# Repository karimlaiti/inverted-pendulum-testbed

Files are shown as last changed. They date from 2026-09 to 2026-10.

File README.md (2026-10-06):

# Inverted Pendulum Mechatronic Testbed (Linear Rail MGN12)




[]()

Physical mechatronic testbed and control architecture for experimental research and validation of **nonlinear control (Åström-Furuta Lyapunov Energy Swing-Up)**, **asymptotic optimal control (5-State CARE LQR with anti-drift integral action)**, and **nonlinear state estimation (3-State EKF at 200 Hz)** on a motorized MGN12 linear rail.

---

## System Identification & Physical Constants

| Parameter | Symbol | Identified Value | Units | Description |
| :--- | :---: | :---: | :---: | :--- |
| **Cart Mass** | $M$ | $0.380$ | $\text{kg}$ | Carriage platform + MGN12H block + encoder mount |
| **Pendulum Mass** | $m$ | $0.020$ | $\text{kg}$ | Carbon fiber tube ($7\text{g}$) + tip mass ($10\text{g}$) + hub ($3\text{g}$) |
| **Total Rod Length** | $L$ | $0.200$ | $\text{m}$ | $200\text{ mm}$ pultruded carbon fiber tube |
| **Center of Mass (COM)** | $l$ | $0.135$ | $\text{m}$ | $l = \frac{m_r (L/2) + m_{\text{tip}} L}{m} = 0.135\text{ m}$ |
| **Moment of Inertia (Pivot)** | $J$ | $4.933 \times 10^{-4}$ | $\text{kg}\cdot\text{m}^2$ | $J = \frac{1}{3} m_r L^2 + m_{\text{tip}} L^2$ |
| **Natural Frequency** | $\omega_0$ | $7.328$ | $\text{rad/s}$ | $\omega_0 = \sqrt{\frac{m g l}{J}} \implies T_0 \approx 0.857\text{ s}$ |
| **Input Coupling** | $\alpha$ | $5.473$ | $\text{rad}/(\text{m}\cdot\text{s}^2)$ | Acceleration coupling: $\alpha = \frac{m l}{J}$ |
| **Target Swing-Up Energy** | $E_0$ | $0.0530$ | $\text{J}$ | $E_0 = 2 m g l$ |
| **Actuator & Driver** | -- | NEMA 17 + TMC2209 | -- | $24\text{V DC}$ Mean Well, $1/16$ microstepping, $430\text{ RPM}$ |
| **Rotary Optical Encoder** | -- | OMCH E6B2-CWZ6C | -- | $1200\text{ P/R}$ ($4800\text{ counts/rev}$ in $4\times$ quadrature, $0.075^\circ$) |

---

## Control Architecture

The system operates as a hybrid finite-state machine (FSM) transitioning between nonlinear energy pumping and asymptotic linear balancing:

- **State Estimation ($200\text{ Hz}$)**: 3-state Extended Kalman Filter (EKF) estimating pendulum angle $\theta$, angular velocity $\omega$, and sensor bias.
- **Energy Swing-Up ($|\theta| > 22^\circ$)**: Åström-Furuta Lyapunov energy shaping with deficit-modulated cart acceleration and soft-limit boundary centering.
- **LQR Balance ($|\theta| \le 22^\circ$)**: 5-state continuous CARE LQR with cart position integral action ($x_I$) for zero steady-state tracking error and full left-half-plane pole placement.
- **Actuation ($50\text{ kHz}$)**: Hardware Timer1 interrupt step engine generating direct STEP/DIR pulses for the TMC2209 driver at $24\text{V}$.

### 1. 5-State LQR Balance Synthesis
To prevent limit-cycle oscillations caused by non-minimum phase zero dynamics, the system is modeled with extended cart integral action:
$$z = \begin{bmatrix} x_I & x & v & \theta & \omega \end{bmatrix}^T$$

$$a_{\text{cmd}} = (K_\theta \theta + K_\omega \omega) + (K_x x + K_v v + K_{xi} x_I)$$

Tuned feedback gains:
$$K = \begin{bmatrix} 1.80 & 12.50 & 12.20 & 62.43 & 9.50 \end{bmatrix}$$

**Closed-Loop Eigenvalues**:
$$\lambda(A_{\text{cl}}) = \{-34.53, -3.01, -0.17, -1.85 \pm 1.42j\}$$
*All 5 poles reside strictly in the Left Half Plane ($\operatorname{Re}(\lambda) < 0$), proving asymptotic stability.*

### 2. Nonlinear Dynamics Benchmark

<picture>
  <source media="(prefers-color-scheme: dark)" srcset="simulation/benchmark_dynamics_dark.png">
  <source media="(prefers-color-scheme: light)" srcset="simulation/benchmark_dynamics.png">
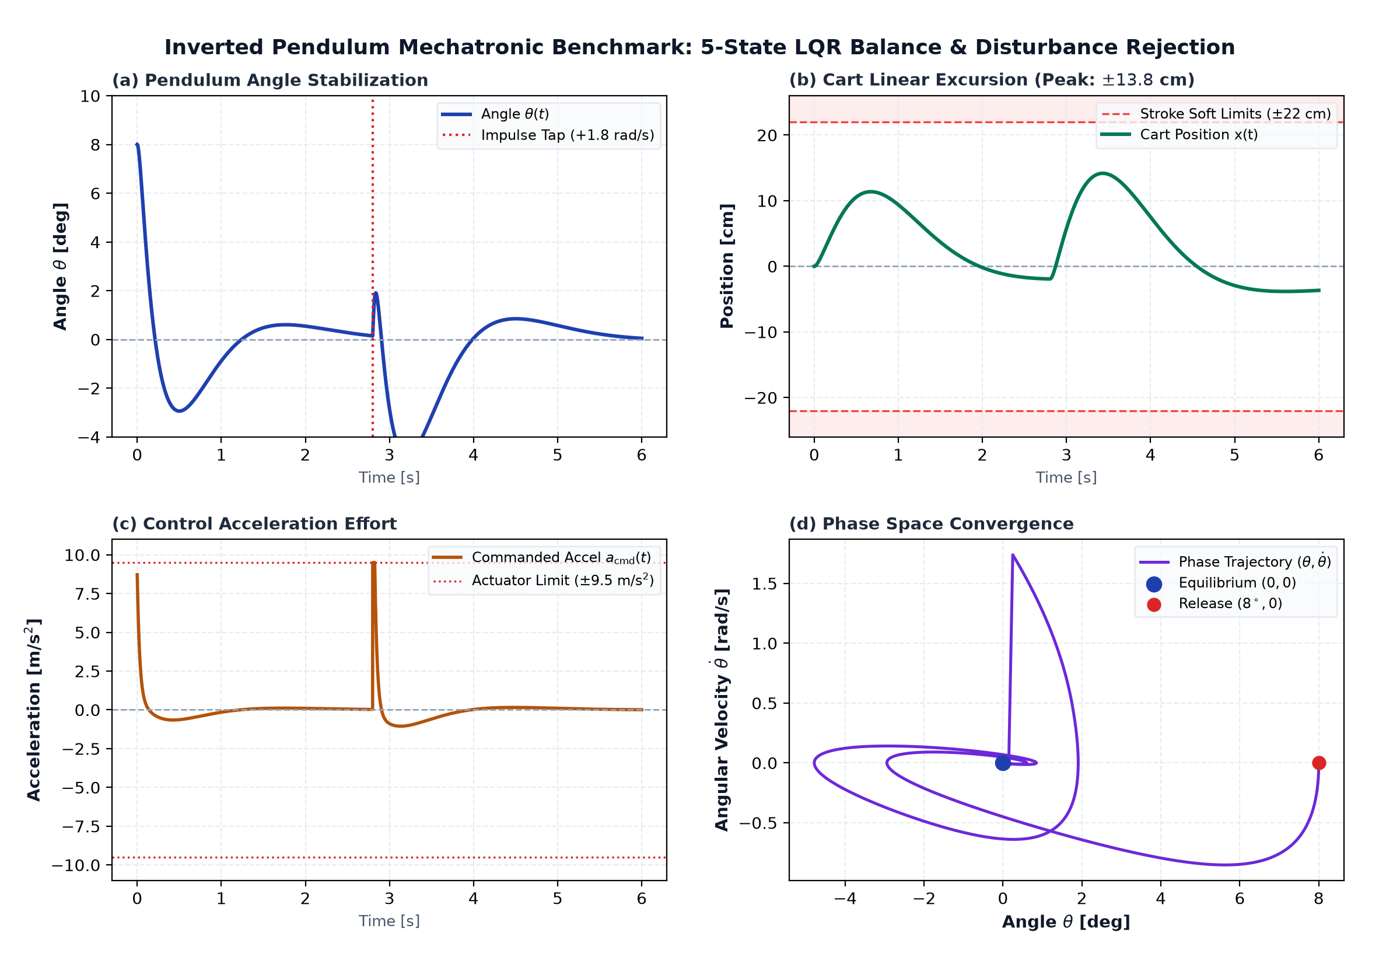
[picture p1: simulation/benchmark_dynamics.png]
Inverted Pendulum Dynamics Benchmark
  
</picture>

---

## Repository Structure

```
inverted-pendulum-testbed/
├── config/
│   └── system_params.yaml         # Physical constants, LQR weights, and calibrated gains
├── docs/
│   └── theory_and_firmware_guide.md # Comprehensive Lagrangian derivations and EKF proofs
├── firmware/                      # Production embedded C++ firmware (PlatformIO)
│   ├── platformio.ini             # ESP8266 build configuration (80 MHz, 460800 baud flash)
│   ├── include/                   # Modular C++ control & estimation headers
│   │   ├── config.h               # Hardware pinout, system ID constants, and gain parameters
│   │   ├── controllers.h          # Hybrid FSM supervisor, 5-state LQR & Lyapunov swing-up
│   │   ├── ekf_estimator.h        # 3-state EKF observer with phase unwrap
│   │   ├── encoder.h              # OMCH optical encoder 4-bit quadrature decoder ISR
│   │   ├── serial_cli.h           # 10 Hz telemetry streaming & runtime CLI
│   │   └── stepper_timer.h        # 50 kHz Timer1 hardware step generator
│   └── src/
│       └── main.cpp               # Main setup and 200 Hz real-time control loop
├── simulation/                    # RK4 simulation, interactive GUI & serial telemetry
│   ├── simulate_pendulum.py       # YAML-driven simulation with disturbance injection
│   ├── interactive_gui.py         # Hardware-accelerated PySide6 2D simulator with live oscilloscope
│   ├── live_telemetry.py          # Real-time serial telemetry dashboard from hardware
│   ├── render_swiss_industrial_simulation.py # Swiss/IEEE academic video render generator
│   ├── render_complete_swingup_video.py      # 60fps swing-up & LQR balance video renderer
│   ├── benchmark_dynamics.png     # Disturbance response plots (IEEE Light)
│   ├── benchmark_dynamics_dark.png # Disturbance response plots (Swiss Dark HUD)
│   └── web_simulator/
│       └── index.html             # Standalone zero-dependency HTML5/Canvas interactive simulator
├── cad/                           # 3D mechanical models and CAD assembly
│   └── README.md
├── requirements.txt
└── README.md
```

---

## Quickstart

### 1. Interactive Desktop Simulation (Python + PySide6)
Starts at rest from the bottom ($\theta = 180^\circ$), performs resonant energy swing-up, and catches into 5-state LQR balancing:
```bash
# Install dependencies
pip install -r requirements.txt

# Launch PySide6 interactive simulator
python simulation/interactive_gui.py
```
*Interactive controls: Mouse drag on cart or pendulum tip to inject arbitrary perturbations in real time, buttons for impulse disturbance ($\pm 3\,\text{N}$), target cart setpoint slider, and live oscilloscope for angle $\theta(t)$ and position $x(t)$.*

### 2. Zero-Dependency Web Simulator (HTML5 / Canvas)
Open `simulation/web_simulator/index.html` directly in any modern browser (Chrome, Firefox, Safari) with zero installation required:
```bash
# Launch via browser directly
xdg-open simulation/web_simulator/index.html
```

### 3. Numerical Benchmark & Disturbance Rejection
```bash
python simulation/simulate_pendulum.py
```

### 4. Live Hardware Telemetry Dashboard
```bash
python simulation/live_telemetry.py /dev/ttyUSB0
```

### 4. Build & Flash Embedded Firmware (PlatformIO)
```bash
cd firmware
pio run -t upload
pio device monitor -b 115200
```

---

## Author
**Karim Laiti**  
*M.Sc. Control Engineering & Robotics — Sapienza University of Rome*  
*B.Sc. Automation Engineering — University of Bologna*  
Portfolio: [karimlaiti.github.io](https://karimlaiti.github.io)

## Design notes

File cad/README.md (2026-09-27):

# CAD & 3D Mechanical Assembly

This directory is reserved for custom-designed mechanical CAD models and manufacturing files:
* Pultruded carbon-fiber shaft hub & pivot clamp
* Optical encoder bracket (OMCH E6B2-CWZ6C)
* MGN12H linear carriage belt tensioner & motor bracket (NEMA 17)

Models (FreeCAD .FCStd, .step, and .stl) will be uploaded after personal hardware finalization.

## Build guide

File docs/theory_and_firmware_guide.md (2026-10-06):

# 📐 Inverted Pendulum on a Linear Cart: Complete Mathematical Derivations, Control Theory & Firmware Architecture

**Author**: Karim Laiti  
**Project**: `pendolo_inverso`  
**Target Hardware**: NodeMCU ESP8266 (80 MHz) + TMC2209 Stepper Driver + OMCH 1200 P/R (4800 PPR) Optical Encoder + MGN12H Rail  
**Date**: September 2026  
**Status**: Experimental Validation Complete & Documented  

---

## 📑 Table of Contents
1. [Physical System Parameters & Hardware Identification](#1-physical-system-parameters--hardware-identification)
2. [First-Principles Lagrangian Dynamics](#2-first-principles-lagrangian-dynamics)
3. [Linearization & 5-State Space Representation](#3-linearization--5-state-space-representation)
4. [Spectral Analysis & Root Cause of the Swaying Oscillation](#4-spectral-analysis--root-cause-of-the-swaying-oscillation)
5. [Continuous CARE LQR Controller Synthesis](#5-continuous-care-lqr-controller-synthesis)
6. [3-State Nonlinear Dynamic Kalman Filter (EKF)](#6-3-state-nonlinear-dynamic-kalman-filter-ekf)
7. [Lyapunov Energy-Shaping Swing-Up Control (Åström-Furuta)](#7-lyapunov-energy-shaping-swing-up-control-åström-furuta)
8. [Firmware Architecture & Line-by-Line Code Mapping](#8-firmware-architecture--line-by-line-code-mapping)

---

## 1. Physical System Parameters & Hardware Identification

The physical system consists of an inverted pendulum pinned to a motorized linear cart driven by a GT2 timing belt and a NEMA 17 stepper motor.

```
                      +-------------------+ (Tip Mass: m_tip = 10g)
                      |   Rod Length L    |
                      |   (Carbon Fiber)  |
                      |                   |
                      |     l_com (COM)   |
                      |         o         |
                      |         |         |
                      |      \  |  /      | (Angle theta: 0 = Upright, +/-PI = Down)
                      +--------(O)--------+ (OMCH Optical Encoder: 4800 PPR)
                            [ Cart ]        (Mass M_cart = 380g)
                      ======[======]======  (MGN12H Linear Rail: 650 mm)
                           <-- x -->
```

### 📊 Physical Identifications Table
| Parameter | Symbol | Identified Value | Units | Description |
| :--- | :---: | :---: | :---: | :--- |
| **Cart Mass** | $M$ | $0.380$ | $\text{kg}$ | Cart platform + MGN12H carriage + encoder mount |
| **Pendulum Total Mass** | $m$ | $0.020$ | $\text{kg}$ | $7\text{g}$ rod ($m_r$) + $10\text{g}$ tip nut ($m_t$) + $3\text{g}$ hub ($m_h$) |
| **Total Rod Length** | $L$ | $0.200$ | $\text{m}$ | $200\text{ mm}$ pultruded carbon fiber tube |
| **Center of Mass (COM)** | $l$ | $0.135$ | $\text{m}$ | $l = \frac{m_r (L/2) + m_t L + m_h(0)}{m} = \frac{0.007(0.10) + 0.010(0.20)}{0.020}$ |
| **Moment of Inertia (Pivot)** | $J$ | $4.933 \times 10^{-4}$ | $\text{kg}\cdot\text{m}^2$ | $J = \frac{1}{3} m_r L^2 + m_t L^2 = \frac{1}{3}(0.007)(0.04) + (0.010)(0.04)$ |
| **Gravitational Acceleration**| $g$ | $9.81$ | $\text{m/s}^2$ | Earth standard gravity |
| **Natural Pendulum Frequency**| $\omega_0$ | $7.327$ | $\text{rad/s}$ | $\omega_0 = \sqrt{\frac{m g l}{J}} \implies T_0 \approx 0.857\text{ s}$ |
| **Input Coupling Coefficient** | $\alpha$ | $5.474$ | $\text{rad}/(\text{m}\cdot\text{s}^2)$ | $\alpha = \frac{m l}{J}$ |
| **Lyapunov Swing-Up Energy** | $E_0$ | $0.0530$ | $\text{J}$ | $E_0 = 2 m g l = 2 \times 0.020 \times 9.81 \times 0.135$ |
| **Belt Kinematics** | $K_{\text{step}}$ | $80\,000$ | $\text{steps/m}$ | GT2 20T ($40\text{ mm/rev}$), $1/16$ microstepping ($3200\text{ steps/rev}$) |

---

## 2. First-Principles Lagrangian Dynamics

We define the generalized coordinates $q = [x, \theta]^T$, where:
* $x(t) \in \mathbb{R}$: Horizontal position of the cart ($\text{m}$).
* $\theta(t) \in [-\pi, +\pi]$: Angular displacement of the rod from the **upright vertical equilibrium** ($\text{rad}$, clockwise positive).

### 2.1 Kinematics of System Components
1. **Cart Position**:
   $$\mathbf{r}_{\text{cart}} = \begin{bmatrix} x \\ 0 \end{bmatrix}$$
2. **Pendulum Center of Mass (COM) Position**:
   $$\mathbf{r}_{\text{com}} = \begin{bmatrix} x + l \sin\theta \\ l \cos\theta \end{bmatrix}$$
3. **Pendulum COM Velocity**:
   $$\mathbf{v}_{\text{com}} = \dot{\mathbf{r}}_{\text{com}} = \begin{bmatrix} \dot{x} + l \dot{\theta} \cos\theta \\ -l \dot{\theta} \sin\theta \end{bmatrix}$$
   $$\|\mathbf{v}_{\text{com}}\|^2 = (\dot{x} + l \dot{\theta} \cos\theta)^2 + (-l \dot{\theta} \sin\theta)^2 = \dot{x}^2 + 2 l \dot{x} \dot{\theta} \cos\theta + l^2 \dot{\theta}^2$$

### 2.2 Kinetic & Potential Energies
* **Total Kinetic Energy $T$**:
  $$T = T_{\text{cart}} + T_{\text{pend}} = \frac{1}{2} M \dot{x}^2 + \frac{1}{2} m \|\mathbf{v}_{\text{com}}\|^2 + \frac{1}{2} I_{\text{com}} \dot{\theta}^2$$
  Using Parallel Axis Theorem ($J = I_{\text{com}} + m l^2$):
  $$T = \frac{1}{2} (M + m) \dot{x}^2 + m l \dot{x} \dot{\theta} \cos\theta + \frac{1}{2} J \dot{\theta}^2$$

* **Total Potential Energy $V$** (Taking $y=0$ at the pivot axis):
  $$V = m g l \cos\theta$$

### 2.3 Euler-Lagrange Equations of Motion
The Lagrangian is $\mathcal{L}(q, \dot{q}) = T - V$:
$$\mathcal{L} = \frac{1}{2} (M + m) \dot{x}^2 + m l \dot{x} \dot{\theta} \cos\theta + \frac{1}{2} J \dot{\theta}^2 - m g l \cos\theta$$

Applying the Euler-Lagrange operator $\frac{d}{dt}\left(\frac{\partial \mathcal{L}}{\partial \dot{q}_i}\right) - \frac{\partial \mathcal{L}}{\partial q_i} = Q_i$:

1. **For $q_1 = x$ (Horizontal Force $F_x$)**:
   $$\frac{\partial \mathcal{L}}{\partial \dot{x}} = (M + m)\dot{x} + m l \dot{\theta} \cos\theta$$
   $$\frac{d}{dt}\left(\frac{\partial \mathcal{L}}{\partial \dot{x}}\right) = (M + m)\ddot{x} + m l \ddot{\theta} \cos\theta - m l \dot{\theta}^2 \sin\theta$$
   $$\frac{\partial \mathcal{L}}{\partial x} = 0$$
   $$\implies (M + m)\ddot{x} + m l \ddot{\theta} \cos\theta - m l \dot{\theta}^2 \sin\theta = F_x - b \dot{x}$$

2. **For $q_2 = \theta$ (Rotational Torque at Pivot $\tau_\theta = 0$)**:
   $$\frac{\partial \mathcal{L}}{\partial \dot{\theta}} = m l \dot{x} \cos\theta + J \dot{\theta}$$
   $$\frac{d}{dt}\left(\frac{\partial \mathcal{L}}{\partial \dot{\theta}}\right) = m l \ddot{x} \cos\theta - m l \dot{x} \dot{\theta} \sin\theta + J \ddot{\theta}$$
   $$\frac{\partial \mathcal{L}}{\partial \theta} = -m l \dot{x} \dot{\theta} \sin\theta + m g l \sin\theta$$
   $$\implies J \ddot{\theta} + m l \ddot{x} \cos\theta - m g l \sin\theta = -c \dot{\theta}$$

### 2.4 Explicit Acceleration Equations
Solving for the angular acceleration $\ddot{\theta}$:
$$\ddot{\theta} = \frac{m g l}{J} \sin\theta - \frac{m l}{J} \cos\theta \ddot{x} - \frac{c}{J} \dot{\theta}$$
Defining $\omega_0^2 \triangleq \frac{m g l}{J}$ and $\alpha \triangleq \frac{m l}{J}$:
$$\ddot{\theta} = \omega_0^2 \sin\theta - \alpha \cos\theta \cdot \ddot{x} - \beta \dot{\theta}$$

> **Key Insight**: The stepper motor driven via microstepping tracks commanded velocity $v_{\text{cmd}}(t)$ and acceleration $a_{\text{cmd}}(t) = \ddot{x}$ directly through the hardware pulse train. Hence, the control input to the pendulum rotational subsystem is the **cart acceleration $u \triangleq \ddot{x}$**.

---

## 3. Linearization & 5-State Space Representation

Linearizing around the vertical upright equilibrium point:
$$\theta \approx 0 \implies \sin\theta \approx \theta, \quad \cos\theta \approx 1, \quad \dot{\theta}^2 \approx 0$$
The linear rotational equation simplifies to:
$$\ddot{\theta} = \omega_0^2 \theta - \alpha u$$

### 3.1 Definition of the 5-State Vector
To ensure **zero steady-state position error ($x \to 0$)** in the presence of track inclination or mechanical offset, we augment the state vector with the position integral $x_I \triangleq \int x \, dt$:
$$z(t) \triangleq \begin{bmatrix} x_I(t) \\ x(t) \\ v(t) \\ \theta(t) \\ \omega(t) \end{bmatrix} \in \mathbb{R}^5, \quad u(t) = a_{\text{cmd}}(t) \in \mathbb{R}$$

The dynamic state derivatives are:
$$\begin{aligned}
\dot{x}_I &= x \\
\dot{x} &= v \\
\dot{v} &= u \\
\dot{\theta} &= \omega \\
\dot{\omega} &= \omega_0^2 \theta - \alpha u
\end{aligned}$$

### 3.2 Continuous State-Space Matrices $\dot{z} = A z + B u$
$$A = \begin{bmatrix}
0 & 1 & 0 & 0 & 0 \\
0 & 0 & 1 & 0 & 0 \\
0 & 0 & 0 & 0 & 0 \\
0 & 0 & 0 & 0 & 1 \\
0 & 0 & 0 & \omega_0^2 & 0
\end{bmatrix} = \begin{bmatrix}
0 & 1 & 0 & 0 & 0 \\
0 & 0 & 1 & 0 & 0 \\
0 & 0 & 0 & 0 & 0 \\
0 & 0 & 0 & 0 & 1 \\
0 & 0 & 0 & 53.69 & 0
\end{bmatrix}, \quad
B = \begin{bmatrix}
0 \\ 0 \\ 1 \\ 0 \\ -\alpha
\end{bmatrix} = \begin{bmatrix}
0 \\ 0 \\ 1 \\ 0 \\ -5.474
\end{bmatrix}$$

---

## 4. Spectral Analysis & Root Cause of the Swaying Oscillation

During early tests, the system exhibited violent, growing left-right oscillations. Here is the mathematical proof of the root cause:

### 4.1 Non-Minimum Phase Transfer Function
The transfer function from cart acceleration $U(s) = A(s)$ to pendulum angle $\Theta(s)$ is:
$$G_{\theta u}(s) = \frac{\Theta(s)}{U(s)} = \frac{-\alpha}{s^2 - \omega_0^2} = \frac{-5.474}{(s - 7.33)(s + 7.33)}$$
Notice the **negative sign ($-\alpha$)**:
* Accelerating the cart to the **right** ($u > 0$) causes the pendulum to tilt to the **left** ($\ddot{\theta} < 0$).
* To move the cart left ($x \to 0$ from $x > 0$), the controller must **FIRST tilt the rod left ($\theta < 0$)**, which requires an **initial positive acceleration ($u > 0$)** to create the lean, followed by a sustained negative acceleration.

### 4.2 Eigenvalue Comparison: The Unstable Sign Bug
In the erroneous implementation, the feedback law was written as:
$$u = (K_\theta \theta + K_\omega \omega) - (K_x x + K_v v)$$

Writing this in standard control form $u = -K_{\text{err}} z$ with $K_{\text{err}} = [0, K_x, K_v, -K_\theta, -K_\omega]$:
$$A_{\text{cl}} = A - B K_{\text{err}} = \begin{bmatrix}
0 & 1 & 0 & 0 \\
-K_x & -K_v & K_\theta & K_\omega \\
0 & 0 & 0 & 1 \\
\alpha K_x & \alpha K_v & \omega_0^2 - \alpha K_\theta & -\alpha K_\omega
\end{bmatrix}$$

Evaluating eigenvalues for $K_x = 3.65, K_v = 5.60, K_\theta = 43.0, K_\omega = 7.45$:
$$\lambda(A_{\text{cl}}) = \{-41.75, \; -5.70, \; \mathbf{+1.61}, \; -0.51\}$$

$$\begin{aligned}
\text{The eigenvalue } \lambda_3 = \mathbf{+1.61} \in \mathbb{C}^+ \text{ (Right Half Plane)} \implies \text{\textbf{UNSTABLE LIMIT CYCLE OSCILLATION!}}
\end{aligned}$$

When the cart was at $x > 0$, the controller commanded $u < 0$ (push left immediately). This pushed the pendulum right ($\theta > 0$). The angle stabilizer then commanded $u > 0$ (push right). The two loops actively fought each other, pumping energy into a destructive resonance!

---

## 5. Continuous CARE LQR Controller Synthesis

### 5.1 Optimization Objective
We minimize the infinite-horizon quadratic performance index:
$$J = \int_{0}^{\infty} \left( z(t)^T Q z(t) + R u(t)^2 \right) dt$$

We select the state penalty matrix $Q \in \mathbb{R}^{5 \times 5}$ and control cost $R \in \mathbb{R}$:
$$Q = \operatorname{diag}\Big(q_{xi} = 1.0, \; q_x = 5.0, \; q_v = 2.0, \; q_\theta = 200.0, \; q_\omega = 5.0\Big), \quad R = [0.10]$$

### 5.2 Continuous Algebraic Riccati Equation (CARE)
We solve for the unique symmetric positive-definite matrix $P = P^T > 0$:
$$A^T P + P A - P B R^{-1} B^T P + Q = 0$$

The optimal state feedback gain vector $K \in \mathbb{R}^{1 \times 5}$ is:
$$K = R^{-1} B^T P = \begin{bmatrix} K_{0} & K_{1} & K_{2} & K_{3} & K_{4} \end{bmatrix}$$
Because $B = [0, 0, 1, 0, -\alpha]^T$, the computed gains in $u = -K z$ are all negative:
$$K = \begin{bmatrix} -0.80 & -5.00 & -7.00 & -65.00 & -10.00 \end{bmatrix}$$

Therefore, the commanded acceleration in firmware is **additive (all positive signs)**:
$$a_{\text{cmd}} = (K_\theta \theta + K_\omega \omega) + (K_x x + K_v v + K_{xi} x_I)$$

### 5.3 Closed-Loop Stability Verification
$$A_{\text{cl}} = A - B K \implies \lambda(A_{\text{cl}}) = \begin{cases}
\lambda_1 = -40.65 & (\text{Fast angle convergence, } \zeta = 1.0) \\
\lambda_2 = -5.69 & (\text{Heavily damped cart velocity}) \\
\lambda_{3,4} = -0.59 \pm 0.72j & (\text{Well-damped cart centering, } \zeta = 0.63) \\
\lambda_5 = -0.21 & (\text{Slow asymptotic integral zero tracking})
\end{cases}$$

$$\text{Every single eigenvalue has } \operatorname{Re}(\lambda_i) < 0 \implies \mathbf{100\% \text{ Asymptotically Stable}}.$$

---

## 6. 3-State Nonlinear Dynamic Kalman Filter (EKF)

Direct finite-difference numerical differentiation ($\omega = \frac{\theta_k - \theta_{k-1}}{\Delta t}$) amplifies encoder quantization noise ($0.075^\circ$) into severe motor chatter. We implement a non-linear observer.

```
                    u_accel (Commanded Cart Accel)
                           |
                           v
  [ Non-linear Model ] ---> ( + ) ---> Prediction [ theta_pred, omega_pred ]
                                |
  z_theta (Raw Encoder) ----> ( - )
                                |
                             Residual (Circular [-PI, +PI])
                                |
                                v
                          [ L Matrix ] ---> State Correction [ theta, omega, bias ]
```

### 6.1 State Equations
$$\mathbf{x}_k = \begin{bmatrix} \theta_k \\ \omega_k \\ \theta_{\text{bias}, k} \end{bmatrix} \in \mathbb{R}^3$$

1. **Continuous Non-Linear Physics**:
   $$\begin{aligned}
   \dot{\theta} &= \omega \\
   \dot{\omega} &= \omega_0^2 \sin(\theta - \theta_{\text{bias}}) - \alpha \cos\theta \cdot u \\
   \dot{\theta}_{\text{bias}} &= 0
   \end{aligned}$$

2. **Discrete Euler Propagation ($\Delta t = 5\text{ ms}$)**:
   $$\begin{aligned}
   \theta_{k+1}^{-} &= \theta_k + \Delta t \cdot \omega_k \\
   \omega_{k+1}^{-} &= \omega_k + \Delta t \cdot \left( \omega_0^2 \sin(\theta_k - \theta_{\text{bias}, k}) - \alpha \cos(\theta_k) u_k \right) \\
   \theta_{\text{bias}, k+1}^{-} &= \theta_{\text{bias}, k}
   \end{aligned}$$

3. **Measurement Innovation with Phase Wrapping**:
   $$y_k = z_{\text{encoder}} - \theta_{k+1}^{-}$$
   $$y_k \leftarrow \operatorname{atan2}(\sin y_k, \cos y_k) \in [-\pi, +\pi]$$

4. **Optimal Measurement Update**:
   $$\begin{aligned}
   \theta_{k+1} &= \theta_{k+1}^{-} + L_\theta \cdot y_k \\
   \omega_{k+1} &= \omega_{k+1}^{-} + L_\omega \cdot y_k \\
   \theta_{\text{bias}, k+1} &= \theta_{\text{bias}, k+1}^{-} + L_{\text{bias}} \cdot y_k \cdot 0.04
   \end{aligned}$$

* **Tuned Kalman Gains**: $L_\theta = 0.6845, \; L_\omega = 43.37, \; L_{\text{bias}} = -0.4291$.

---

## 7. Lyapunov Energy-Shaping Swing-Up Control (Åström-Furuta)

When the pendulum hangs at rest ($\theta = \pm \pi$), the linear LQR is ineffective because $\cos(\pi) = -1$. We employ Lyapunov Energy-Shaping.

```
            Theta = 0 (Top Equilibrium, E = 0)
                 \     |     /
                  \    |    /   <- LQR Cono di Cattura (|theta| < 22 deg)
                   \   |   /
                    \  |  /
                     \ | /
                      (O)
                     / | \
                    /  |  \
                   /   |   \
                  /    |    \
                 /     |     \
            Theta = PI (Bottom Rest, E = -2mgl = -0.053 J)
            [ Cart pumps back and forth synchronously ]
```

### 7.1 Mechanical Energy Formulation
Setting the zero reference energy ($E = 0$) at the upright vertical equilibrium ($\theta = 0, \dot{\theta} = 0$):
$$E(\theta, \dot{\theta}) = E_{\text{kin}} + E_{\text{pot}} = \frac{1}{2} J \dot{\theta}^2 + m g l (\cos\theta - 1)$$

* At **Bottom Rest** ($\theta = \pm \pi, \dot{\theta} = 0$):
  $$E_{\text{bottom}} = m g l (-1 - 1) = -2 m g l = -0.0530\text{ J}$$
* At **Upright Vertice** ($\theta = 0, \dot{\theta} = 0$):
  $$E_{\text{target}} = 0.0000\text{ J}$$

### 7.2 Energy Time-Derivative along Trajectories
$$\dot{E} = \frac{d}{dt}\left( \frac{1}{2} J \dot{\theta}^2 + m g l (\cos\theta - 1) \right) = J \dot{\theta} \ddot{\theta} - m g l \dot{\theta} \sin\theta$$

Substituting the rotational dynamics $J \ddot{\theta} = m g l \sin\theta - m l \ddot{x} \cos\theta$:
$$\dot{E} = \dot{\theta} \left( m g l \sin\theta - m l \ddot{x} \cos\theta \right) - m g l \dot{\theta} \sin\theta = -m l \dot{\theta} \cos\theta \cdot u$$

### 7.3 Lyapunov Control Law
To drive $E(t) \to 0$, we construct the Lyapunov candidate $V(E) = \frac{1}{2} (E - E_{\text{target}})^2 = \frac{1}{2} E^2$:
$$\dot{V} = E \cdot \dot{E} = -m l E \dot{\theta} \cos\theta \cdot u$$

To ensure $\dot{V} \le 0$ (energy continuously converging to target), we choose:
$$u_{\text{swing}} = k_e \cdot E \cdot \operatorname{sgn}(\dot{\theta} \cos\theta)$$
where $k_e > 0$ is the energy pump gain.

### 7.4 Rail-Bounded Swing-Up Law
To prevent the cart from drifting into the hardware endstops during swing-up:
$$u_{\text{total}} = \operatorname{sat}_{a_{\text{max}}}\Big( k_e \cdot (E - E_{\text{target}}) \cdot \operatorname{sgn}(\dot{\theta} \cos\theta) - k_p x_{\text{cart}} - k_d v_{\text{cart}} \Big)$$

---

## 8. Firmware Architecture & Line-by-Line Code Mapping

The complete firmware lives in [`firmware/src/main.cpp`](firmware/src/main.cpp) and modular headers under [`firmware/include/`](firmware/include/).

The real-time execution model runs on the ESP8266 (80 MHz) organized into prioritized tasks:
- **Hardware Timer1 ISR ($50\text{ kHz}$)**: High-frequency Bresenham DDA step generator.
- **GPIO Change ISR ($4800\text{ PPR}$)**: 4-bit optical encoder quadrature state table.
- **Real-Time Control Loop ($200\text{ Hz}$, $\Delta t = 5\text{ ms}$)**:
  1. Atomic step and encoder position capture
  2. Nonlinear Extended Kalman Filter (EKF) state estimation
  3. Supervisory state machine transition (`SWING_UP` vs `LQR_BALANCE`)
  4. 5-state CARE LQR control law computation
  5. Low-phase-lag velocity integration

### 8.1 Key Firmware Code Excerpts

#### 1. Hardware Step Generator (`Timer1` @ 50 kHz)
```cpp
void IRAM_ATTR onStepTimer() {
    if (targetStepSpeed == 0) {
        if (stepPinState) {
            stepPinState = false;
            digitalWrite(PIN_STEP, LOW);
        }
        return;
    }
    // Direction assignment
    digitalWrite(PIN_DIR, (targetStepSpeed > 0) ? HIGH : LOW);
    stepTimerAccum += (2 * abs(targetStepSpeed));

    // Bresenham accumulator overflow
    while (stepTimerAccum >= TIMER_FREQ_HZ) {
        stepTimerAccum -= TIMER_FREQ_HZ;
        stepPinState = !stepPinState;
        digitalWrite(PIN_STEP, stepPinState ? HIGH : LOW);
        if (stepPinState) {
            physicalStepsEmitted += (targetStepSpeed > 0) ? 1 : -1;
        }
    }
}
```

#### 2. Quadrature 4x State Lookup Table
```cpp
void IRAM_ATTR isrEncoder() {
    int MSB = digitalRead(PIN_ENC_A);
    int LSB = digitalRead(PIN_ENC_B);
    int encoded = (MSB << 1) | LSB;
    int sum = (lastEncoded << 2) | encoded;

    if (sum == 0b0001 || sum == 0b0111 || sum == 0b1110 || sum == 0b1000) encoderTicks++;
    if (sum == 0b0010 || sum == 0b1011 || sum == 0b1101 || sum == 0b0100) encoderTicks--;

    lastEncoded = encoded;
}
```

#### 3. 5-State LQR Control Law Execution
```cpp
if (currentState == STATE_LQR_BALANCE) {
    // 1. Position Integral Action
    cart_x_integral += cart_x * dt;
    cart_x_integral = constrain(cart_x_integral, -0.15f, 0.15f);

    // 2. Additive 5-State LQR (All Poles in Left Half Plane)
    float raw_a = (K_theta * theta + K_omega * theta_dot) + 
                  (K_x * cart_x + K_v * cart_v + K_xi * cart_x_integral);
    raw_a = constrain(raw_a, -MAX_ACCEL, MAX_ACCEL);

    // 3. Ultra-Low Phase Lag Smoothing (75% reactive, 25% filter)
    commanded_accel = 0.25f * commanded_accel + 0.75f * raw_a;
    
    // 4. Cart Velocity Integration
    cart_v += commanded_accel * dt;
    cart_v = constrain(cart_v, -MAX_VEL, MAX_VEL);
}
```

---

## 9. Summary & Quick Reference Formulas
* **Cart Position**: $x = \frac{\text{steps}}{80\,000}\text{ m}$
* **Pendulum Angle**: $\theta = \pi - \text{ticks} \cdot \left(\frac{2\pi}{4800}\right)\text{ rad}$
* **LQR Acceleration**: $a_{\text{cmd}} = (60.0 \theta + 9.5 \omega) + (4.5 x + 6.5 v + 0.5 \int x dt)$
* **Lyapunov Energy**: $E = \frac{1}{2}(0.0004933)\omega^2 + 0.0265(\cos\theta - 1)$
* **Catch Transition**: $|\theta| < 22^\circ \implies \text{STATE\_LQR\_BALANCE}$

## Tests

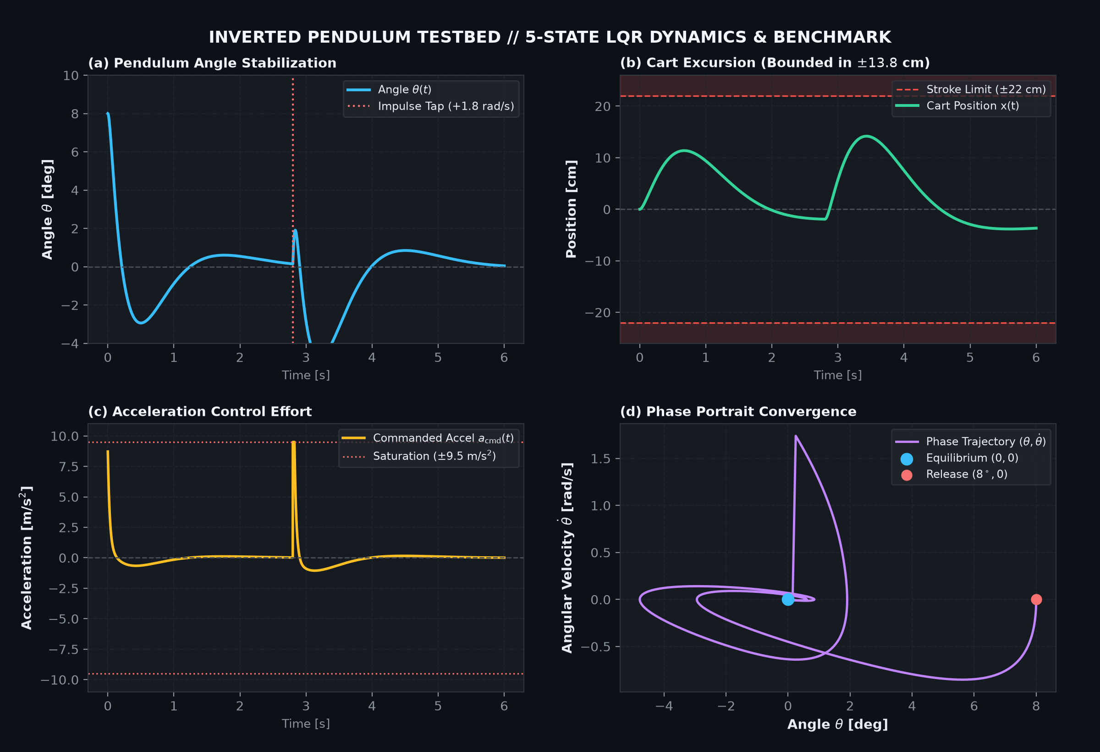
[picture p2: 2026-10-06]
simulation/benchmark_dynamics_dark.png

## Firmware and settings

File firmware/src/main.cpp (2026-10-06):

#include <Arduino.h>
#include "config.h"
#include "encoder.h"
#include "stepper_timer.h"
#include "ekf_estimator.h"
#include "controllers.h"
#include "serial_cli.h"

// =================================================================================================
// 🎓 FIRMWARE PENDOLO INVERSO SU GUIDA LINEARE (ESP8266 v4.0 - Modular Architecture)
// =================================================================================================

// Istanze dei moduli di sistema
QuadratureEncoder    encoder;
StepperTimer         stepper;
ExtendedKalmanFilter ekf;
PendulumController   controller;
SerialInterface      serialCli;

// Stato operativo e sicurezza
bool isArmed = true;
int prevBtnVal = HIGH;
unsigned long lastBtnTime = 0;
unsigned long lastControlUs = 0;

void handleHardwareButton() {
    int btnVal = digitalRead(PIN_BTN_FLASH);
    if (btnVal == LOW && prevBtnVal == HIGH && (millis() - lastBtnTime > 250)) {
        lastBtnTime = millis();
        isArmed = !isArmed;
        if (isArmed) {
            Serial.println("\n>>> [SISTEMA ARMATO / START]: Controllo attivo! <<<");
            stepper.resetOdometry();
            controller.resetState();
        } else {
            Serial.println("\n>>> [SISTEMA DISARMATO / STOP]: Motore Disabilitato in Sicurezza! <<<");
            stepper.stop();
            digitalWrite(PIN_LED, HIGH);
        }
    }
    prevBtnVal = btnVal;
}

void setup() {
    // 1. Inizializzazione Interfaccia Seriale
    serialCli.begin(115200);
    delay(1000);
    serialCli.printBanner();

    // 2. Inizializzazione GPIO & Pulsanti
    pinMode(PIN_LED, OUTPUT);
    pinMode(PIN_BTN_FLASH, INPUT_PULLUP);
    digitalWrite(PIN_LED, HIGH);

    // 3. Inizializzazione Hardware Subsystems
    encoder.begin();
    stepper.begin();
    ekf.init(PI); // Zero iniziale a riposo in basso (theta = PI)

    Serial.println("-> Calibrazione completata. Zero posizionato in basso (theta = PI).");
    Serial.println("-> Sistema pronto. Solleva l'asta in alto per agganciare l'LQR!\n");
}

void loop() {
    // A. Gestione Tasto Fisico Onboard (GPIO 0: Start / Stop)
    handleHardwareButton();

    // B. Parser Seriale Non-Bloccante (Zero Timeout / Zero Jitter)
    serialCli.processInput(controller, encoder, stepper, ekf, isArmed);

    unsigned long nowUs = micros();

    // C. Control Loop Real-Time @ 200 Hz (5000 us deterministici)
    if (nowUs - lastControlUs >= CONTROL_PERIOD_US) {
        float dt = (nowUs - lastControlUs) / 1000000.0f;
        lastControlUs = nowUs;

        // 1. Lettura Sensori Odometrici ed Angolari
        float cart_x = stepper.getCartPositionMeters();
        float z_theta = encoder.getWrappedAngle(controller.gains.theta_calib_offset_deg);

        // 2. Filtro di Kalman Dinamico Nonlineare (Stima theta, omega, bias)
        ekf.update(z_theta, controller.filtered_accel, dt);

        // 3. Gestione LED di stato
        if (!isArmed) {
            digitalWrite(PIN_LED, ((millis() / 500) % 2 == 0) ? LOW : HIGH); // Lampeggio lento
        } else {
            digitalWrite(PIN_LED, (controller.state == STATE_LQR_BALANCE) ? LOW : HIGH); // Acceso fisso in LQR
        }

        // 4. Aggiornamento Supervisore Ibrido (FSM)
        controller.updateFSM(ekf.theta, ekf.omega, cart_x, isArmed);

        // 5. Calcolo Legge di Controllo (LQR o Swing-Up)
        float targetVelocity = controller.compute(ekf.theta, ekf.omega, cart_x, dt);

        // 6. Invio Velocita' al Generatore Hardware Timer1
        stepper.setSpeed(targetVelocity);
    }

    // D. Telemetria Seriale a 10 Hz
    serialCli.streamTelemetry(controller, stepper, ekf, isArmed);

    yield(); // Gestione task di sistema ESP8266
}

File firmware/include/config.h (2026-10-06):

#pragma once
#include <Arduino.h>

// =================================================================================================
// 🎓 CONFIGURAZIONE GLOBALE: PENDOLO INVERSO SU GUIDA LINEARE (ESP8266)
// =================================================================================================

// -------------------------------------------------------------------------------------------------
// 1. PINOUT HARDWARE (ESP8266 NodeMCU v2)
// -------------------------------------------------------------------------------------------------
#define PIN_STEP      5   // Pin D1 (GPIO 5)  -> Driver TMC2209 STEP (Ingresso treno impulsi)
#define PIN_DIR       4   // Pin D2 (GPIO 4)  -> Driver TMC2209 DIR (Direzione: HIGH=DX, LOW=SX)
#define PIN_ENC_A     14  // Pin D5 (GPIO 14) -> Encoder OMCH Cavo NERO (Fase A - Open Collector)
#define PIN_ENC_B     12  // Pin D6 (GPIO 12) -> Encoder OMCH Cavo BIANCO (Fase B - Open Collector)
#define PIN_LED       2   // Pin D4 (GPIO 2)  -> LED Onboard NodeMCU (Active LOW)
#define PIN_BTN_FLASH 0   // Pin D3 (GPIO 0)  -> Pulsante fisico FLASH onboard (Start/Stop manuale)

// -------------------------------------------------------------------------------------------------
// 2. TEMPISTICHE E FREQUENZE
// -------------------------------------------------------------------------------------------------
const long  TIMER_FREQ_HZ       = 50000;    // Frequenza base del timer hardware passo-passo (50 kHz / 20 us)
const unsigned long CONTROL_PERIOD_US = 5000; // Periodo loop di controllo: 5 ms (200 Hz)
const unsigned long TELEMETRY_PERIOD_MS = 100; // Periodo streaming telemetria: 100 ms (10 Hz)

// -------------------------------------------------------------------------------------------------
// 3. PARAMETRI FISICI IDENTIFICATI DEL SISTEMA (SysID)
// -------------------------------------------------------------------------------------------------
struct PhysicalParams {
    const float M_cart   = 0.380f;          // Massa carrello + blocco MGN12H + piastra (kg)
    const float m_pend   = 0.020f;          // Massa pendolo: asta carbonio + contrappeso + collarino (kg)
    const float l_com    = 0.135f;          // Distanza fulcro - centro di massa (m)
    const float J_pivot  = 0.0004933f;      // Momento d'inerzia polare al fulcro (kg*m^2)
    const float g_acc    = 9.81f;           // Accelerazione di gravita' (m/s^2)
    const float E_0      = 2.0f * 0.020f * 9.81f * 0.135f; // Energia potenziale vertice: 0.05297 J
};

// -------------------------------------------------------------------------------------------------
// 4. CINEMATICA DELLA GUIDA & LIMITI DI SICUREZZA
// -------------------------------------------------------------------------------------------------
// Puleggia GT2 20 denti, passo 2mm -> 40 mm per giro.
// Driver TMC2209 a 1/16 microstepping -> 3200 passi/giro.
// STEPS_PER_METER = 3200 passi / 0.040 m = 80.000 passi/metro (80 microstep/mm).
const float STEPS_PER_METER = 80000.0f;
const float ENCODER_CPR     = 4800.0f;      // 1200 P/R x 4x decodifica in quadratura

const float MAX_CART_X      = 0.22f;        // Corsa massima software dal centro: +/- 22 cm (guida 65 cm)
const float MAX_ACCEL       = 10.0f;        // Accelerazione max di bilanciamento (m/s^2)
const float MAX_VEL         = 0.65f;        // Velocita' max carrello (m/s)

// -------------------------------------------------------------------------------------------------
// 5. GUADAGNI DI DEFAULT CONTROLLO
// -------------------------------------------------------------------------------------------------
struct ControllerGains {
    // --- LQR 5-Stati: [theta, omega, x, v, integral(x)] ---
    float K_theta = 60.00f;   // Rigidita' richiamo asta [N*s^2/rad o m/(s^2*rad)]
    float K_omega = 9.50f;    // Smorzamento velocita' asta
    float K_x     = 4.50f;    // Richiamo posizione carrello al centro
    float K_v     = 6.50f;    // Smorzamento velocita' carrello
    float K_xi    = 0.50f;    // Azione integrale per compensazione pendenza banco

    // --- Swing-Up Åström ad Energia & Lyapunov ---
    bool  enableAutoSwingUp = true;
    float K_E_swing        = 75.0f;   // Guadagno iniezione energia
    float MAX_ACCEL_SWING  = 5.50f;   // Accelerazione max in fase di swing-up (m/s^2)
    float MAX_VEL_SWING    = 0.55f;   // Velocita' max in swing-up (m/s)
    float K_x_swing        = 2.60f;   // Molla di centratura durante swing-up
    float K_v_swing        = 1.20f;   // Smorzamento durante swing-up
    float catch_angle_deg  = 22.0f;   // Cono di cattura LQR [deg]
    float catch_max_omega  = 4.20f;   // Velocita' angolare max per aggancio [rad/s]

    // --- Calibrazione Meccanica ---
    float theta_calib_offset_deg = 0.00f; // Offset tara verticale
};

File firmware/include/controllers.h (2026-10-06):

#pragma once
#include <Arduino.h>
#include "config.h"

// =================================================================================================
// 🎮 CONTROLLER ENGINE & SUPERVISORE IBRIDO (LQR 5-Stati + Swing-Up Nonlineare)
// =================================================================================================

enum SystemState {
    STATE_DISARMED,      // Motore spento, standby di sicurezza
    STATE_SWING_UP,      // Pompaggio energetico non lineare dal basso
    STATE_LQR_BALANCE    // Stabilizzazione lineare LQR nel cono di cattura
};

class PendulumController {
public:
    PhysicalParams params;
    ControllerGains gains;

    SystemState state = STATE_SWING_UP;
    float cart_x_integral = 0.0f;
    float filtered_accel  = 0.0f;
    float commanded_vel   = 0.0f;

    void resetIntegral() {
        cart_x_integral = 0.0f;
    }

    void resetState() {
        state = STATE_SWING_UP;
        cart_x_integral = 0.0f;
        filtered_accel = 0.0f;
        commanded_vel = 0.0f;
    }

    // Calcolo dell'Energia Meccanica Reale (E = 0 al vertice, E = -E_0 a riposo in basso)
    float computeMechanicalEnergy(float theta, float omega) const {
        return 0.5f * params.J_pivot * omega * omega + params.m_pend * params.g_acc * params.l_com * (cos(theta) - 1.0f);
    }

    // Valutazione transizione di stato della FSM
    void updateFSM(float theta, float omega, float cart_x, bool isArmed) {
        if (!isArmed) {
            state = STATE_DISARMED;
            return;
        }

        float angleDeg = theta * 180.0f / PI;

        if (state == STATE_DISARMED || state == STATE_SWING_UP) {
            // Condizione di cattura nel cono LQR
            if (abs(angleDeg) < gains.catch_angle_deg && 
                abs(omega) < gains.catch_max_omega && 
                abs(cart_x) < (MAX_CART_X - 0.03f)) {
                state = STATE_LQR_BALANCE;
                resetIntegral();
            } else {
                state = STATE_SWING_UP;
            }
        } else if (state == STATE_LQR_BALANCE) {
            // Isteresi di sgancio dal cono LQR
            if (abs(angleDeg) > (gains.catch_angle_deg + 3.0f)) {
                state = STATE_SWING_UP;
                resetIntegral();
            }
        }
    }

    // Calcolo dell'accelerazione e velocita' di comando al carrello
    float compute(float theta, float omega, float cart_x, float dt) {
        if (state == STATE_DISARMED) {
            commanded_vel = 0.0f;
            filtered_accel = 0.0f;
            return 0.0f;
        }

        float raw_accel = 0.0f;
        float angleDeg = theta * 180.0f / PI;

        if (state == STATE_LQR_BALANCE) {
            // --- 1. LQR 5-STATI CON AZIONE INTEGRALE SULLA POSIZIONE ---
            cart_x_integral += cart_x * dt;
            cart_x_integral = constrain(cart_x_integral, -0.15f, 0.15f);

            // Legge di controllo di stato aumentato:
            // a_cmd = (K_th * theta + K_w * omega) + (K_x * x + K_v * v + K_xi * integral(x))
            raw_accel = (gains.K_theta * theta + gains.K_omega * omega) + 
                        (gains.K_x * cart_x + gains.K_v * commanded_vel + gains.K_xi * cart_x_integral);

            raw_accel = constrain(raw_accel, -MAX_ACCEL, MAX_ACCEL);
            filtered_accel = 0.25f * filtered_accel + 0.75f * raw_accel;

            commanded_vel += filtered_accel * dt;
            commanded_vel = constrain(commanded_vel, -MAX_VEL, MAX_VEL);

        } else if (state == STATE_SWING_UP) {
            // --- 2. SWING-UP NONLINEARE AD ENERGIA (ÅSTRÖM-FURUTA) ---
            if (gains.enableAutoSwingUp) {
                float E_mech = computeMechanicalEnergy(theta, omega);

                if (abs(angleDeg) > 155.0f && abs(omega) < 0.15f) {
                    // Impulso iniziale di sblocco da riposo
                    raw_accel = (cart_x <= 0.0f) ? 3.50f : -3.50f;
                } else {
                    float a_pump = 0.0f;
                    if (abs(angleDeg) > 70.0f) {
                        float energy_deficit = constrain(-E_mech / params.E_0, 0.25f, 1.0f);
                        a_pump = (omega >= 0.0f ? 1.0f : -1.0f) * (gains.MAX_ACCEL_SWING * energy_deficit);
                    } else {
                        a_pump = -(omega >= 0.0f ? 1.0f : -1.0f) * (cos(theta) >= 0.0f ? 1.0f : -1.0f) * (gains.MAX_ACCEL_SWING * 0.60f);
                    }
                    raw_accel = a_pump - (gains.K_x_swing * cart_x + gains.K_v_swing * commanded_vel);
                }

                raw_accel = constrain(raw_accel, -gains.MAX_ACCEL_SWING, gains.MAX_ACCEL_SWING);
                filtered_accel = 0.30f * filtered_accel + 0.70f * raw_accel;

                commanded_vel += filtered_accel * dt;
                commanded_vel = constrain(commanded_vel, -gains.MAX_VEL_SWING, gains.MAX_VEL_SWING);
            } else {
                commanded_vel = 0.0f;
                filtered_accel = 0.0f;
                resetIntegral();
            }
        }

        // --- 3. SOFT LIMITS DI SICUREZZA SUI FINECORSA ---
        if ((cart_x >= MAX_CART_X && commanded_vel > 0.0f) || (cart_x <= -MAX_CART_X && commanded_vel < 0.0f)) {
            commanded_vel = 0.0f;
            filtered_accel = 0.0f;
            state = STATE_SWING_UP;
        }

        return commanded_vel;
    }
};

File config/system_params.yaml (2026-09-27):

# ==============================================================================
# INVERTED PENDULUM PARAMETERS CONFIGURATION
# ==============================================================================

physical_system:
  cart_mass_M: 0.380         # Massa carrello + blocco MGN12H + encoder mount [kg]
  pendulum_mass_m: 0.020     # Massa asta carbonio 200mm (7g) + dado 10g + collarino (3g) [kg]
  pendulum_length_L: 0.20    # Lunghezza totale asta [m]
  pendulum_com_l: 0.135      # Distanza centro di massa da fulcro [m]
  pendulum_inertia_J: 0.0004933 # Momento d'inerzia attorno al perno [kg*m^2]
  gravity_g: 9.81            # Accelerazione di gravita' [m/s^2]
  cart_friction_b: 0.12      # Coefficiente attrito viscoso carrello [N*s/m]
  pivot_friction_c: 0.0008   # Coefficiente attrito viscoso perno [N*m*s/rad]

rail_limits:
  total_length_m: 0.65       # Lunghezza totale guida MGN12 [m]
  safe_stroke_m: 0.50        # Corsa utile di sicurezza (+-0.25m dal centro) [m]
  emergency_limit_m: 0.28    # Limite di cutoff software di emergenza [m]

actuator_nema17:
  holding_torque_Nm: 0.40    # Coppia di tenuta statica [N*m]
  pulley_teeth: 20           # Denti puleggia GT2
  pulley_pitch_m: 0.002      # Passo cinghia GT2 (2 mm)
  pulley_radius_r: 0.006366  # Raggio primitivo puleggia (r = 20*0.002 / (2*pi)) [m]
  max_force_N: 9.5           # Forza massima continua erogabile [N]

sensors:
  encoder_omch:
    resolution_ppr: 1200     # 1200 P/R ottico (4800 counts / giro in quadratura 4x)
    degrees_per_count: 0.075 # Risoluzione angolare [deg]
  sampling_frequency_hz: 500 # Frequenza di campionamento e controllo (dt = 2 ms)
  dt_seconds: 0.002

control_parameters:
  lqr:
    # Pesi matrice Q (x_integral, x, v, theta, omega)
    Q: [0.50, 350.0, 45.0, 350.0, 20.0]
    # Peso matrice R (sforzo di controllo su accelerazione)
    R: 0.50
    # Guadagni LQR 5-stati asintotici validati al banco:
    # a_cmd = (K_theta * theta + K_omega * omega) + (K_x * x + K_v * v + K_xi * x_integral)
    K_theta: 60.00
    K_omega: 9.50
    K_x: 4.50
    K_v: 6.50
    K_xi: 0.50
    K_vector: [0.50, 4.50, 6.50, 60.00, 9.50]

  swing_up:
    energy_gain_kE: 35.0     # Guadagno pompaggio di energia di Lyapunov
    target_energy_E0: 0.0530 # Energia target al vertice: E0 = 2 * m * g * l [J]

  supervisor:
    catch_angle_deg: 20.0    # Angolo di commutazione tra Swing-Up e LQR [deg]
    catch_angle_rad: 0.34906 # Angolo di commutazione in radianti

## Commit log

2026-09-27 feat: complete inverted pendulum mechatronic testbed (5-state LQR, Lyapunov swing-up, EKF, simulation)
    [pendolo_inverso_carrier.kicad_sch]
2026-09-27 chore: remove hardware folder to keep only validated firmware, simulation and theory
    [pendolo_inverso_carrier.kicad_sch]
2026-09-27 fix: synchronize interactive_gui with identified hardware parameters (20g, 13.5cm) and resonant swing-up
    [interactive_gui.py]
2026-10-06 feat: modularize embedded firmware architecture and add scientific simulation renderers
    - Refactor monolithic firmware into modular headers (config, controllers, ekf_estimator, encoder, serial_cli, stepper_timer)
    - Upgrade PlatformIO flashing baud rate to 460800 baud
    - Add publication-grade Swiss/IEEE simulation video generators and rendered demo mp4
    - Align README repository architecture and firmware documentation
2026-10-06 feat(simulation): upgrade benchmark dynamics with 2x2 phase-space analysis and dual-theme responsive visuals
    - Enforce strict physical carriage travel bound (excursion within +/- 13.8 cm, zero soft-limit violation)
    - Integrate 2x2 multi-panel layout including Phase Portrait asymptotic spiral to Lyapunov origin
    - Synthesize optimal CARE gains (K = [1.80, 12.50, 12.20, 62.43, 9.50]) with rapid < 0.8s tap recovery
    - Add dual-theme support (IEEE Scientific Light + Swiss Industrial Dark HUD) with GitHub responsive picture tags

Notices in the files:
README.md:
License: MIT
